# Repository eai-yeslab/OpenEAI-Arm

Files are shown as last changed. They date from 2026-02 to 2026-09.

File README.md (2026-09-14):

# OpenEAI-Arm

Open-source, low-cost, reproducible desktop robot hardware for embodied AI and real-world manipulation.

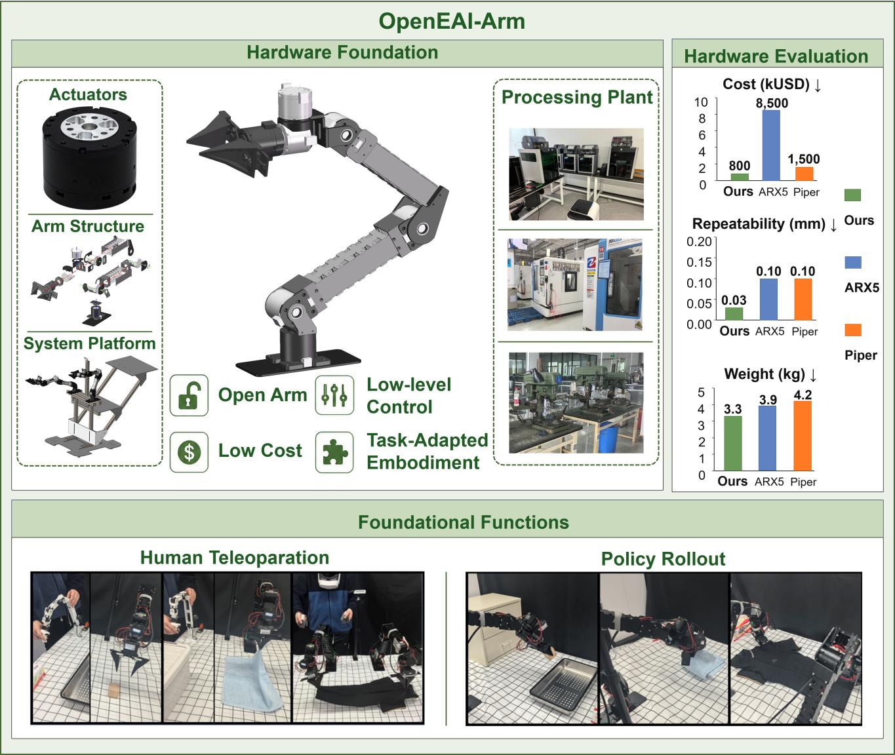
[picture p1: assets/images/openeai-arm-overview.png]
OpenEAI-Arm overview


OpenEAI-Arm is a 6-DoF serial robot arm with an independently controlled end-effector channel. It is designed for embodied-AI research, robot-control development, real-world policy evaluation, teleoperation, and Vision-Language-Action (VLA) data collection. The repository provides the mechanical design, manufacturing files, robot model, low-level control stack, ROS 2 integration, teleoperation examples, and data-collection tools needed to reproduce and extend the platform.

The design prioritizes a practical balance among workspace, payload, mass, manufacturability, control access, and cost. It can be used as a complete experimental platform or as an open hardware foundation for replacing actuators, modifying links, integrating new end effectors, and building synchronized dual-arm systems.

> [!WARNING]
> A robot arm can move unexpectedly and generate hazardous forces. Rigidly secure the base, keep the workspace clear, verify the emergency stop, and begin with simulation followed by unloaded, low-speed, small-angle tests. Never hot-plug the 24 V power or CAN wiring.

## OpenEAI Ecosystem

OpenEAI-Arm is the robot-hardware and control foundation of the OpenEAI platform:

- [OpenEAI-VLA](https://github.com/eai-yeslab/OpenEAI-VLA) provides the Vision-Language-Action research and deployment stack.
- [OpenEAI-FOC](https://github.com/ZJYSII/OpenEAI-FOC) develops open joint hardware, drive electronics, sensing, and field-oriented motor control.
- OpenEAI-Arm connects policies to a reproducible physical system through kinematics, dynamics-aware control, CAN communication, ROS 2, teleoperation, and safety limits.

```text
OpenEAI-VLA policy and data pipeline
                  │ actions
                  ▼
OpenEAI-Arm coordination, kinematics, teleoperation, and safety
                  │ joint targets
                  ▼
OpenEAI-FOC / compatible joint actuators and end effector
                  │
                  └──────── joint state and sensor feedback ────────┘
```

## Highlights

### Open hardware

- Six rotary joints plus one independently controlled end-effector channel
- Modular actuators, links, base, cable routing, and end-effector interface
- BOM, STEP, STL, mechanical drawings, URDF/SDF, and assembly documentation
- Replaceable gripper, dexterous-hand, or sensor interface
- Suitable for single-arm, dual-arm, and task-adapted embodiments

### Open control stack

- C++ core library, Python bindings, and ROS 2 nodes
- CAN-based joint and end-effector communication
- Joint-space, end-effector incremental, and end-effector absolute-pose control
- Gravity, inertia, Coriolis, and friction compensation in the low-level stack
- Jerk-limited S-curve interpolation for smoother target execution
- Simulation and visualization through the shared robot model

### Teleoperation and embodied-AI workflows

- GELLO master-slave joint control
- SpaceMouse incremental Cartesian control
- VR absolute-pose teleoperation over UDP
- Single-arm and dual-arm operation with isolated configurations and topics
- Synchronized image, joint-state, and action collection for VLA datasets
- Policy rollout examples for real-world manipulation

## System Specifications

The following values describe the documented OpenEAI-Arm V0.9 prototype. Payload, speed, accuracy, and thermal performance depend on assembly quality, calibration, controller settings, end-effector mass, and operating conditions.

| Parameter | Specification |
| --- | --- |
| Active degrees of freedom | 6 |
| End-effector control channels | 1 |
| Maximum reach | 636.7 mm |
| Arm mass | 3.3 kg, excluding gripper |
| Nominal end payload | 2 kg, excluding gripper |
| Nominal power | 420 W |
| Peak current | 17.5 A |
| Theoretical maximum end-effector speed | 1.6 m/s |
| Rated joint torque | J1-J3: 9 N·m; J4-J7: 3 N·m |
| Maximum static joint torque | J1-J3: 27 N·m; J4-J7: 7 N·m |
| Prototype repeatability | ±0.03 mm |
| Gripper force range | 0.5-5 N |
| Joint and end-effector bus | CAN |
| Power input | 24 V DC, XT30 2+2 |
| Documented manufacturing cost | Approximately CNY 5,500 |
| Recommended environment | 0-40 °C; non-waterproof |

The comparison charts in the overview image are project evaluation results. When reproducing them, report the hardware revision, payload, trajectory, warm-up state, measurement equipment, sample count, and calculation method.

## Kinematics

The controller uses Modified Denavit-Hartenberg parameters matching the CAD and URDF. The fixed mechanical angle is `β = 13.85°`.

| Joint | θ (deg) | a (mm) | d (mm) | α (deg) |
| --- | ---: | ---: | ---: | ---: |
| J1, base rotation | 0 | 0 | 106.26 | 0 |
| J2, shoulder pitch | 180 | 19 | 0 | -90 |
| J3, elbow flexion | 180 + β | 269 | 0 | 180 |
| J4, wrist deviation | -β | 236.12 | 0 | 0 |
| J5, wrist pitch | 90 | 80 | 0 | 90 |
| J6, tool rotation | 0 | 0 | 29 | 90 |

The end-effector mounting envelope is approximately 57 mm × 35 mm and uses four M3 fasteners. Communication and power can be routed through the final joint using the CAN and XT30 2+2 harness.

## Repository Layout

```text
OpenEAI-Arm/
├─ hardware/
│  ├─ bom/                    # Bill of materials
│  ├─ STEP/                   # Assemblies and manufacturable CAD
│  ├─ stl/                    # Printable and visualization meshes
│  ├─ drawings/               # DWG/PDF manufacturing drawings
│  └─ assembly/               # Assembly documentation
├─ software/
│  ├─ configs/                # Arm, CAN, motor, zero, and limit settings
│  ├─ include/ and src/       # C++ control library
│  ├─ python/                 # Python bindings
│  ├─ ros2/                   # ROS 2 nodes, robot model, and examples
│  ├─ scripts/                # Visualization and utility scripts
│  └─ tests/                  # Hardware and software test programs
├─ assets/                    # README images and videos
├─ LICENSE
└─ THIRD_PARTY_NOTICES
```

- Hardware index: [`hardware/README.md`](hardware/README.md)
- Software, control, and teleoperation guide: [`software/README.md`](software/README.md)
- Default real-arm configuration: [`software/configs/default.yml`](software/configs/default.yml)
- ROS 2 node: [`software/ros2/src/openeai_arm/src/OpenEAIArm_node.cpp`](software/ros2/src/openeai_arm/src/OpenEAIArm_node.cpp)
- Control and data-collection examples: [`software/ros2/src/openeai_arm/examples/`](software/ros2/src/openeai_arm/examples/)

## Quick Start

### 1. Prepare the system

Ubuntu 22.04 and ROS 2 Humble are recommended.

```bash
sudo apt update
sudo apt install git build-essential cmake libyaml-cpp-dev libeigen3-dev liburdf-dev

git clone https://github.com/eai-yeslab/OpenEAI-Arm.git
cd OpenEAI-Arm/software
```

A Python 3.10 environment is recommended for keeping robot dependencies isolated:

```bash
conda create -n openeai python=3.10
conda activate openeai
```

Pinocchio, KDL, the Dynamixel SDK, and optional teleoperation dependencies require additional setup. Follow [`software/README.md`](software/README.md) before building the complete stack.

### 2. Build

Build the C++ library, ROS 2 packages, and Python bindings from the `software/` directory:

```bash
cmake -S . -B build -DCMAKE_BUILD_TYPE=Release
cmake --build build --target extra -j 8
```

To build the components separately:

```bash
# C++ core and tests
cmake -S . -B build -DCMAKE_BUILD_TYPE=Release
cmake --build build -j 8

# Python package
cmake -S . -B build -DCMAKE_BUILD_TYPE=Release \
  -DPYTHON_EXECUTABLE=$(python3 -c "import sys; print(sys.executable)")
cmake --build build --target pip_install -j 8

# ROS 2 workspace
cmake --build build --target ros2
source ros2/install/setup.bash
```

### 3. Verify in simulation first

Terminal 1:

```bash
cd OpenEAI-Arm/software
source ros2/install/setup.bash
ros2 launch openeai_arm_urdf_ros2 launch.py
```

Terminal 2:

```bash
cd OpenEAI-Arm/software
source ros2/install/setup.bash
ros2 run openeai_arm OpenEAIArm_node --ros-args \
  -p ctrl_mode:=2 -p frequency:=50
```

Use simulation to verify the robot model, coordinate frames, joint directions, reachable workspace, and topics. Stop the node before changing between simulation and real-hardware modes.

### 4. Configure the real arm

Before applying power, inspect [`software/configs/default.yml`](software/configs/default.yml):

- Serial device and communication settings
- CAN master/slave IDs for all six joints and the gripper
- Joint zero positions and direction signs
- Position, velocity, acceleration, and torque limits
- URDF path and end-effector configuration

The public default configuration uses `/dev/ttyACM0`, but the actual device path may differ. The first two actuator IDs in the public configuration are intentionally ordered differently from a simple `1, 2, ...` sequence; verify every physical joint against the configuration instead of assuming numeric order.

Add the user to the serial-device group if required, then log out and back in:

```bash
sudo usermod -aG dialout $USER
```

### 5. Start the real arm

Rigidly mount the base, clear the workspace, support the arm against an uncontrolled drop, and make the emergency stop immediately reachable.

```bash
cd OpenEAI-Arm/software
source ros2/install/setup.bash
ros2 run openeai_arm OpenEAIArm_node --ros-args \
  -p ctrl_mode:=0 -p frequency:=50 \
  -p config:=configs/default.yml
```

Inspect the current state before sending any target:

```bash
ros2 topic echo /openeai_arm/joint_states --once
ros2 topic echo /openeai_arm/eef_pose --once
ros2 topic hz /openeai_arm/joint_states
```

The `position` target contains seven values:

```text
[J1, J2, J3, J4, J5, J6, gripper]
```

Read the current position first. For initial motion, copy the current seven-value target and change only one joint by approximately 0.03-0.05 rad. Do not copy joint values from another arm.

## Control Modes

| Function | Settings | Purpose |
| --- | --- | --- |
| Joint position control | `ctrl_mode:=0`, `ee_pose:=0` | Send six joint targets plus gripper |
| Drag teaching | `ctrl_mode:=1` | Manually guide the arm while publishing joint state |
| Simulation | `ctrl_mode:=2` | Validate the model and control interface without motors |
| End-effector increments | `ctrl_mode:=0`, `ee_pose:=1` | Incremental Cartesian commands, typically SpaceMouse |
| Absolute end-effector pose | `ctrl_mode:=0`, `ee_pose:=2` | Absolute pose input, typically VR |

### GELLO master-slave control

```bash
ros2 run openeai_arm OpenEAIArm_node --ros-args \
  -p ctrl_mode:=0 -p frequency:=50 -p arm_name:=left

cd ros2/src/openeai_arm/examples
python gello_controller.py
```

### SpaceMouse control

```bash
sudo apt install libhidapi-dev
pip install git+https://github.com/bglopez/python-easyhid.git
pip install pyspacemouse

ros2 run openeai_arm OpenEAIArm_node --ros-args \
  -p ctrl_mode:=0 -p ee_pose:=1 -p frequency:=50

cd ros2/src/openeai_arm/examples
python spacemouse.py
```

### VR control

The example expects UDP data in the form `[x, y, z, qx, qy, qz, qw, gripper]` at approximately 50 Hz.

```bash
ros2 run openeai_arm OpenEAIArm_node --ros-args \
  -p ctrl_mode:=0 -p ee_pose:=2 -p frequency:=50

cd ros2/src/openeai_arm/examples
python vr.py
```

Validate direction, scale, coordinate frames, and initial-pose alignment in simulation before connecting the real arm.

## Dual-Arm Operation

Use independent device paths, node names, configurations, and target topics. Calibrate and test each arm separately before running both together.

```bash
# Left arm
ros2 run openeai_arm OpenEAIArm_node --ros-args \
  -p ctrl_mode:=0 -p frequency:=50 -p arm_name:=left \
  -r /joint_targets:=/left/joint_targets

# Right arm
ros2 run openeai_arm OpenEAIArm_node --ros-args \
  -p config:=configs/default_right.yml \
  -p ctrl_mode:=0 -p frequency:=50 -p arm_name:=right \
  -r /joint_targets:=/right/joint_targets
```

## VLA Data Collection

The examples support synchronized camera images, joint states, and actions. Start the arm, launch the required USB or RealSense camera nodes, and then run:

```bash
cd ros2/src/openeai_arm/examples
python collect_data.py --task_name pick_place --config config_left.yml
```

For dual-arm capture, see `config_multi.yml`. Record a short sample first and verify timestamps, dimensions, camera views, joint order, action units, and gripper values before collecting a full dataset.

## Recommended Test Sequence

1. Inspect the base, fasteners, cable routing, end effector, work area, and emergency stop.
2. Confirm the device path, CAN IDs, zero positions, direction signs, and limits.
3. Start RViz or drag mode and verify the pose and coordinate conventions.
4. Start the real node and confirm that all seven channels report continuous state.
5. Perform an unloaded, small-angle, single-joint motion test.
6. Run the target function while monitoring communication, current, temperature, and mechanical behavior.
7. Stop teleoperation or policy commands, return to a supported safe pose, and stop the arm node.
8. Confirm that the motors are disabled, support the arm, and disconnect 24 V power before adjustment or disassembly.

Immediately stop and disconnect power after unintended motion, collision, unusual noise, persistent CAN loss, overcurrent, overheating, burning odor, structural looseness, or high-frequency oscillation.

## Frequently Asked Questions

### The serial device cannot be opened

Check the actual `/dev/ttyACM*` or `/dev/ttyUSB*` path, USB cable, group permissions, and `can_config.id`. Reconnect only while power is safely removed, and log in again after changing `dialout` membership.

### A CAN node is missing or repeatedly disconnects

Power down first. Verify the 24 V supply, CAN high/low wiring, termination, bus rate, physical node IDs, and the master/slave IDs in the selected YAML configuration.

### A joint moves in the wrong direction

Use the emergency stop, correct the direction or zero setting in the configuration, and repeat an unloaded low-speed test. Do not compensate for a reversed joint only at the high-level policy layer.

### The arm jitters after startup

Stop motion and check the zero position, direction, encoder installation, structural fasteners, update frequency, and controller gains. Reduce gains and target changes before retesting.

### End-effector control jumps

Check units, reference pose, quaternion convention, coordinate frames, inverse-kinematics result, and initial alignment. Reproduce the command in simulation and reduce the increment or pose change.

### Pinocchio cannot be found

Check the installed Python version and the `PATH`, `PKG_CONFIG_PATH`, `LD_LIBRARY_PATH`, `PYTHONPATH`, and `CMAKE_PREFIX_PATH` entries for `/opt/openrobots`.

### Dual-arm topics interfere with each other

Use separate device paths, configuration files, arm names, node names, namespaces, and remapped target topics. Test each arm independently before enabling simultaneous motion.

## Citation

If OpenEAI-Arm contributes to your research, please cite the OpenEAI-Platform paper and identify the repository version or commit used:

```bibtex
@inproceedings{openeai_platform,
  title  = {OpenEAI-Platform: Open-source Embodied Artificial Intelligence Hardware-Software Unified Platform},
  author = {Jinyuan Zhang and Luoyi Fan and Leiyu Wang and Yeqiang Wang and Yichen Zhu and Cewu Lu and Nanyang Ye},
  year   = {2026}
}
```

## License

OpenEAI-Arm is licensed under the [BSD 3-Clause License](LICENSE). Third-party components remain subject to their respective licenses; see [`THIRD_PARTY_NOTICES`](THIRD_PARTY_NOTICES).

## Contributing and Support

Issues and pull requests are welcome. Include the hardware revision, operating system, configuration, supply conditions, command sequence, logs, and reproducible steps. For safety-related reports, describe the physical setup and tested limits.

- Repository: <https://github.com/eai-yeslab/OpenEAI-Arm>
- Open an issue for questions, bugs, or proposed changes
- Contact: ynylincoln@sjtu.edu.cn

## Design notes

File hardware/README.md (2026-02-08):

# Hardware

This directory contains all hardware-related files for the OpenEAI Arm.

## Directory Structure

- **STEP/** - files in STEP format
- **stl/** - 3D printable STL files
- **drawings/** - CAD drawings in PDF format
- **bom/** - Bill of Materials (XLSX format)
- **assembly/** - Assembly instructions in PDF format

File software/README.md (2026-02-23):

# OpenEAI-ARM

This is the open-source control software for the OpenEAI-ARM robot.

## Prerequisites

First, make sure you have some basic building tools on your machine. You can install them by:

```bash
sudo apt install git build-essential cmake
```

Then, clone the repository:

```bash
git clone https://github.com/eai-yeslab/OpenEAI-Arm.git
```

Since some of the third-party dependencies will use python bindings, we also recommend setting up a python virtual environment to avoid conflicts with your system python packages. You can set up a virtual environment with the following commands:

```bash
conda create -n openeai python=3.10
conda activate openeai
```

## Third-party Dependencies

This project relys on the following third-party packages:
- yaml-cpp for reading config files
- Eigen3 library for matrix calculations
- URDF library for urdf reading
- [pinocchio](https://gepettoweb.laas.fr/doc/stack-of-tasks/pinocchio/master/doxygen-html/md_doc_b_examples_a_model.html) for inverse kinetics
- [KDL](https://www.orocos.org/wiki/orocos/kdl-wiki.html)
- [kdl_parser](https://github.com/ros/kdl_parser?tab=readme-ov-file) and [urdf](https://github.com/ros/urdf) packages, whose source codes are already included so that they can be used without installing ros
- [Dynamixel SDK](https://github.com/ROBOTIS-GIT/DynamixelSDK/tree/main) for controlling [GELLO](https://wuphilipp.github.io/gello_site/)

### yaml-cpp, Eigen3, URDF Installation

Run `sudo apt install libyaml-cpp-dev libeigen3-dev liburdf-dev` to install yaml-cpp, Eigen3, and URDF library.

### Dynamixel SDK Installation

Simply `cd` to its python directory and install:

```bash
cd third_party/DynamixelSDK/python
pip install -e .
```

### Pinocchio Installation

In this project we use pinocchio to calculate inverse kinetics. To install this library run the following commands as described in the [official installation website](https://stack-of-tasks.github.io/pinocchio/download.html#Install_3). Note this may take a while:

```bash
sudo apt install -qqy lsb-release curl

sudo mkdir -p /etc/apt/keyrings
curl http://robotpkg.openrobots.org/packages/debian/robotpkg.asc \
    | sudo tee /etc/apt/keyrings/robotpkg.asc

echo "deb [arch=amd64 signed-by=/etc/apt/keyrings/robotpkg.asc] http://robotpkg.openrobots.org/packages/debian/pub $(lsb_release -cs) robotpkg" \
| sudo tee /etc/apt/sources.list.d/robotpkg.list

sudo apt update

sudo apt install -qqy robotpkg-py3*-pinocchio
```

And then modify the following environment variables or add to `$HOME/.bashrc` for persistent configuration:

```bash
export PATH=/opt/openrobots/bin:$PATH
export PKG_CONFIG_PATH=/opt/openrobots/lib/pkgconfig:$PKG_CONFIG_PATH
export LD_LIBRARY_PATH=/opt/openrobots/lib:$LD_LIBRARY_PATH
export PYTHONPATH=/opt/openrobots/lib/python3.10/site-packages:$PYTHONPATH # Adapt your desired python version here
export CMAKE_PREFIX_PATH=/opt/openrobots:$CMAKE_PREFIX_PATH
```

### KDL Installation

[KDL](https://github.com/orocos/orocos_kinematics_dynamics/tree/master) (Kinetics and Dynamics Library) requires Eigen3 library to install. To install, run the following commands:

```bash
git clone https://github.com/orocos/orocos_kinematics_dynamics.git
cd orocos_kinematics_dynamics/orocos_kdl
mkdir build
cd build
cmake .. -DCMAKE_BUILD_TYPE=Release
make
sudo make install
```

## Build and Installation

In this project, we use cmake to build the control program.

### All

We provide an option to build everything, including basic C++ library, ROS2 pacakge, and python package installation via pip. This can be completed via:

```bash
cmake -S . -B build -DCMAKE_BUILD_TYPE=RELEASE
cmake --build build --target extra
```

If you don't want to build all of them, you can build them one by one following the instructions below.

### C++

C++ libraries are core libraries to control OpenEAI-Arm. The commands are:

```bash
cmake -S . -B build -DCMAKE_BUILD_TYPE=RELEASE
cmake --build build -j 8
```

An example of the usage can be found at [tests/test_openeai_arm.cpp](tests/test_openeai_arm.cpp), whose brinary is located at [build/test_openeai_arm](build/test_openeai_arm). If you want to run it, make sure your robotic arm is well-assembled, as the program will move the robotic arm.

### Python

To build python packages and install via pip, run:
```bash
cmake -S . -B build -DCMAKE_BUILD_TYPE=RELEASE -DPYTHON_EXECUTABLE=$(python3 -c "import sys; print(sys.executable)")
cmake --build build --target pip_install -j 8 
```

### ROS2

ROS2 packages can be built with cmake:

```bash
cmake --build build --target ros2 
```

Or, after run the commands for building C++ libraries, run:

```bash
cd ros2
colcon build --symlink-install
```

After building the package, add it to the environment:

```bash
cd ros2/install # or cd install
source setup.bash
```

And start the arm node:

```bash
cd ../..
ros2 run openeai_arm OpenEAIArm_node --ros-args -p ctrl_mode:=0 -p frequency:=50 # 0 for program control mode, 1 for drag mode, 2 for sim mode
```

You can also set `-p ee_pose:=1` for delta ee pose control, and `-p ee_pose:=2` for absolute ee pose control.

If you want to run two arms at the same time, you can use:

```bash
ros2 run openeai_arm OpenEAIArm_node --ros-args -p ctrl_mode:=0 -p frequency:=50 -p arm_name:=left -r /joint_targets:=/left/joint_targets
ros2 run openeai_arm OpenEAIArm_node --ros-args -p config:=configs/default_right.yml -p ctrl_mode:=0 -p frequency:=50 -p arm_name:=right -r /joint_targets:=/right/joint_targets
```

where [configs/default_right.yml](configs/default_right.yml) is the config file for another arm.

An example of python ROS2 controller can be found at [ros2/src/openeai_arm/examples/OpenEAIArmROS2Operator.py](ros2/src/openeai_arm/examples/OpenEAIArmROS2Operator.py), which provides `get_frame()` function to collect the latest data from robotic arm, cameras, etc. with synchronized timestamps.

To switch the control mode when the node is running, you can publish to the topic `/set_control_mode` with message type `sensor_msgs/msg/JointState`, where the first data is the control mode you want to switch to, 0 for program control mode and 1 for drag mode, where the sim mode does not support switching to and from; and the second data is the ee pose mode, 0 for joint control, 1 for delta ee pose control, and 2 for absolute ee pose control. For example, to switch to drag mode under joint control, you can run:

```bash
ros2 topic pub /set_control_mode sensor_msgs/msg/JointState "header:
  stamp:
    sec: 0
    nanosec: 0
  frame_id: ''
name: []
position: [1.0, 0.0]
velocity: []
effort: []" -1
```

or you can write your own script to publish the message.

## Control

### Basic Settings

To run this control library with your own robotic arm, first assign a unique master id and slave id to each motor, as described in [Damiao's official tutorial](https://gl1po2nscb.feishu.cn/wiki/LjOXwEqNCiqThpk1IIycHoranlb). Next, align the robotic arm to be parallel with the table, and record the positions of the motors. You can either set this position to be the motors' zero points, or record them in the config file.

Then, based on your settings, modify the parameters in the config file. The default config file is stored at `configs/default.yml`, but it is recommanded to create a copy before modifying any options. Some important parameters include:

- `can_config.id` and `can_config.baud_rate`, which is the port path of Damiao's USB2CAN device. 
- `urdf.path` pointing to the urdf path if it is changed
- For each motor, modify `type`, `reset_pose`, `master_id` and `slave_id` if necessary. The motors are from bottem (base) to top (end effector). **Please note in the default setting, the first motor has slave_id to be 0x02, and the second has 0x01, !!modify this based on your own settings!!** 

## Data collection

OpenEAI-arm supports human manipulation for further training. We provide an example data collection code based on ROS2 in [ros2/src/openeai_arm/examples/collect_data.py](ros2/src/openeai_arm/examples/collect_data.py) using , and you can write your own data collection scripts with/without ROS2. 

To run the data collection code in ROS2, first compile the ros2 package as described before. Then, start the arm node and camera node:

```bash
# Start Arm node
ros2 run openeai_arm OpenEAIArm_node --ros-args -p ctrl_mode:=0 -p frequency:=50 -p arm_name:=left -r /joint_targets:=/left/joint_targets

# You should adapt these camera nodes to your own camera settings, here are just some examples

# Start USB Camera node (not recommended, use realsense if possible)
ros2 run usb_cam usb_cam_node_exe --ros-args -p video_device:=/dev/video0 -p image_width:=640 -p image_height:=480 -p framerate:=30.0

# Start Realsense Camera node
ros2 launch realsense2_camera rs_launch.py camera_namespace:=camera camera_name:=agentview depth_module.depth_profile:=640x480x30 rgb_camera.color_profile:=640x480x30 enable_rgbd:=true enable_sync:=true align_depth.enable:=true enable_color:=true enable_depth:=true serial_no:="'335222074022'" # D435i
ros2 launch realsense2_camera rs_launch.py camera_namespace:=camera camera_name:=eyeview depth_module.depth_profile:=640x480x30 depth_module.color_profile:=640x480x30 depth_module.infra_profile:=640x480x30 enable_rgbd:=true enable_sync:=true align_depth.enable:=true enable_color:=true enable_depth:=true serial_no:="'218722270624'" # D405

# Start GELLO controller and Data Collection scripts
cd ros2/src/openeai_arm/examples
python collect_data.py --task_name pick_place --config config_left.yml
```

You can modify the parameters in [ros2/src/openeai_arm/examples/config_left.yml](ros2/src/openeai_arm/examples/config_left.yml) based on your environment in ROS2.

If you want to collect data for two (multiple) arms, refer to [ros2/src/openeai_arm/examples/config_multi.yml](ros2/src/openeai_arm/examples/config_multi.yml) for example config file.

### Control With GELLO

[GELLO manipulation](https://wuphilipp.github.io/gello_site/) is a simple and effective way to control robotic arms. We provide an example code to use GELLO as controller in ROS2. To use it, 
first start the ROS2 arm node in normal mode:

```bash
ros2 run openeai_arm OpenEAIArm_node --ros-args -p ctrl_mode:=0 -p frequency:=50 -p arm_name:=left
```

Then run the following scripts:

```bash
cd ros2/src/openeai_arm/examples
python gello_controller.py
```

This script will connect to GELLO device and broadcast the joint targets to the arm node at topic `/joint_targets`.

### Control With SpaceMouse

We also provide an example code to use spacemouse as controller. To install the dependencies for [pyspacemouse](https://spacemouse.kubaandrysek.cz/#linux), run:

```bash
sudo apt-get install libhidapi-dev
pip install git+https://github.com/bglopez/python-easyhid.git
echo 'KERNEL=="hidraw*", SUBSYSTEM=="hidraw", MODE="0664", GROUP="plugdev"' | sudo tee /etc/udev/rules.d/99-hidraw-permissions.rules
sudo usermod -aG plugdev $USER
newgrp plugdev

pip install pyspacemouse
```

And run scripts in ROS2:

```bash
cd ros2/src/openeai_arm/examples
python spacemouse.py
```

Then, start the ros2 node in delta ee pose mode (set `ee_pose:=1`):

```bash
ros2 run openeai_arm OpenEAIArm_node --ros-args -p ctrl_mode:=0 -p frequency:=50 -p arm_name:=left -r /joint_targets:=/left/joint_targets -p ee_pose:=1
```

### Control With VR

We also provide an example to manipulate the arm with VR devices. To use it you need to have a server program running on your VR device and receive UDP packages in the format described in [ros2/src/openeai_arm/examples/vr.py](ros2/src/openeai_arm/examples/vr.py#48). First, start the ROS2 node for arm in absolute ee pose mode (`ee_pose:=2`):

```bash
ros2 run openeai_arm OpenEAIArm_node --ros-args -p ctrl_mode:=0 -p frequency:=50 -p arm_name:=left -r /joint_targets:=/left/joint_targets -p ee_pose:=2

ros2 run openeai_arm OpenEAIArm_node --ros-args -p config:=configs/default_right.yml -p ctrl_mode:=0 -p frequency:=50 -p arm_name:=right -r /joint_targets:=/right/joint_targets -p ee_pose:=2
```

Then, run `vr.py` to receive and retrieve handle poses to robotic poses:

```bash
python vr.py
```

Hold B to command the arm to prepare position, and release B to start manipulation **after the robotic arm reaches the prepare position and your VR controller is in the correct pose**. Press `A` to stop sending position to the arm until holding and releasing `B` again. Hold `Y` to retract the arm.

**Note:** We recommand you to first using simulation mode to test the VR controlling before manipulating the real arm. set `ctrl_mode:=2` to use simulation mode.

## Simulation

We provide a launch file to launch simulation in ROS2 via rviz2. To start the simulation interface, run:

```bash
ros2 launch openeai_arm_urdf_ros2 launch.py
```

and run ROS2 arm node in sim mode by setting `ctrl_mode` to be 2:

```bash
ros2 run openeai_arm OpenEAIArm_node --ros-args -p ctrl_mode:=2 -p frequency:=50
```

## Inference

To run inference with a trained model, you can use the provided FastAPI server. First, ensure you have a trained model checkpoint, then, modify `CKPT_PATH` in [OpenEAI-VLA/openeai/infer.py](OpenEAI-VLA/openeai/infer.py) to point to your checkpoint path.

Then, start the inference server by running:

```bash
cd ros2/src/openeai_arm/examples
python inference.py --task_instruction "do something" --contiguous --config_path config_left_inference.yml --server_host 127.0.0.1 --server_port 8000
```

You can modify [OpenEAI-Arm/ros2/src/openeai_arm/examples/config_left_inference.yml](OpenEAI-Arm/ros2/src/openeai_arm/examples/config_left_inference.yml) based on your own settings.

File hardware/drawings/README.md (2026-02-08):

# Technical Drawings

This directory contains technical drawings in PDF and DWG format for the OpenEAI Arm.

These drawings provide detailed dimensions and specifications for manufacturing and assembly.

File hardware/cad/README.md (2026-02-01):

# CAD Files

This directory contains CAD files in STEP format for the OpenEAI Arm.

STEP files are industry-standard 3D CAD files that can be opened in most CAD software packages.

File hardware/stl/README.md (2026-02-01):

# STL Files

This directory contains STL files for 3D printing parts of the OpenEAI Arm.

STL files can be used directly with slicing software for 3D printing.

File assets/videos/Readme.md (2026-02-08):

# Videos

This directory contains video content related to the OpenEAI Arm project.

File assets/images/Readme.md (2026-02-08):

# Images

This directory contains images and photos related to the OpenEAI Arm project.

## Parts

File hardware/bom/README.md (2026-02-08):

# Bill of Materials (BOM)

This directory contains the Bill of Materials for the OpenEAI Arm in XLSX format.

The BOM lists all components, quantities, and sourcing information needed to build the arm.

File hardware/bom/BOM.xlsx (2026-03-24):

Material | Subassembly Belongings | Character | Quantity | Price(RMB) | Price(USD) | Purchase
JXS-01-01 | STEP1 | 6061 Aluminum | 1 | <1400 | <200 | Manufacturing
JXS-01-02 | STEP1 |  | 1
JXS-01-03 | STEP1 |  | 1
JXS-01-04 | STEP1 |  | 1
JXS-01-05 | STEP1 |  | 1
JXS-02-01 | STEP2\3 |  | 4
JXS-02-02 | STEP2\3 |  | 4
JXS-02-03 | STEP2 |  | 2
JXS-02-04 | STEP2 |  | 2
JXS-03-01 | STEP3 |  | 1
JXS-03-02 | STEP3 |  | 1
JXS-04-01 | STEP4 |  | 1
JXS-04-02 | STEP4 |  | 1
JXS-04-03 | STEP4 |  | 1
JXS-04-04 | STEP4 |  | 1
JXS-04-05 | STEP4 |  | 1
JXS-04-06 | STEP4 |  | 1
JXS-04-07 | STEP4 |  | 1
JXS-05-01 | STEP5 |  | 1
B6704ZZ | STEP2\3\4 | Bearing Steel | 3 | 10.38 | 1.5 | https://e.tb.cn/h.ia5PtiowQPkVhvE?tk=2lIBUKFAZoj
JXS-07-05 | GRIP | SLA | 1 |  |  | 3D printing
JXS-07-08 | GRIP | SLA | 1 |  |  | 3D printing
JXS-07-09 | GRIP | SLA | 1 |  |  | 3D printing
Clamping Jaw v3 | GRIP | SLA | 1 |  |  | 3D printing
Clamping Jaw v3 left | GRIP | SLA | 1 |  |  | 3D printing
Slider and Rail | GRIP |  | 2 | 76 | 11 | https://e.tb.cn/h.7AGLF0jUZUDXJjp?tk=wZmaUKFiw6g
switch | GRIP | 6061 Aluminum | 1 |  |  | 3D printing
casing2 | STEP2 | SLA | 1 |  |  | 3D printing
casing3 | STEP3 | SLA | 1 |  |  | 3D printing
DAMIAOJ4340 | ALL | motor | 3 | 2544 | 370 | DAMIAO
DAMIAOJ4310-2EC | ALL | motor | 3+1 | 2396 | 348 | DAMIAO
Power source 24V XT30 12A |  | Power Source | 1 | 90 | 13 | https://item.jd.com/10084543367630.html
Parallel Connection XT30 |  | Parallel Connection | 2 | 58 | 8.4 | https://e.tb.cn/h.7A4o7VFhj66tiTt?tk=ocFrUKFQPPY (https://item.taobao.com/item.htm?id=996289044875&skuId=5973666792008)
XT30 2+2 Wire 20cm | ALL |  | 3 | 31.5 | 4.56 | https://e.tb.cn/h.iZhQ6utcLtsRVfZ?tk=sKYsUKE1MLk
XT30 2+2 Wire 20cm straight + bent | ALL |  | 2 | 30 | 4.34
XT30 2+2 Wire 30cm | ALL |  | 3 | 42 | 6.08
Ball head pull rod M3 40mm | GRIP | Steel | 2 | 3.33 | 0.48 | https://e.tb.cn/h.7A4Q9qckt7PgGVO?tk=txeAUKF5MX4
M2screw | ALL | 304 Steel | 200 | ≈6 | ≈1 | https://e.tb.cn/h.ia5ccovAxU8BVyT?tk=qlBiUKFNj23
M3screw | ALL | 304 Steel | 200 | ≈6.5 | ≈1
M5screw | STEP1 | 304 Steel | 200 | ≈7 | ≈1
M3screw2 | ALL | 304 Steel | 100 | ≈3 | ≈0.5 | https://e.tb.cn/h.7AuZkvmwAsdF7XE?tk=TiSiUKFtPge
M3弹垫 | ALL | 304 Steel | 500 | 2.33 | 0.33 | https://e.tb.cn/h.ia57VBTVB2qIsj3?tk=0bYBUKFFsLV
M3螺母 | ALL | 304 Steel | 50 | 1.94 |  | https://e.tb.cn/h.ia58a2TkJB2xWVG?tk=60x6UKFwrnU
Tie 3*200 |  | Nylon | 100 | 7.75 | 2.43 | https://e.tb.cn/h.7Au3DzMf98FGadV?tk=uw8gUKFB4Qe

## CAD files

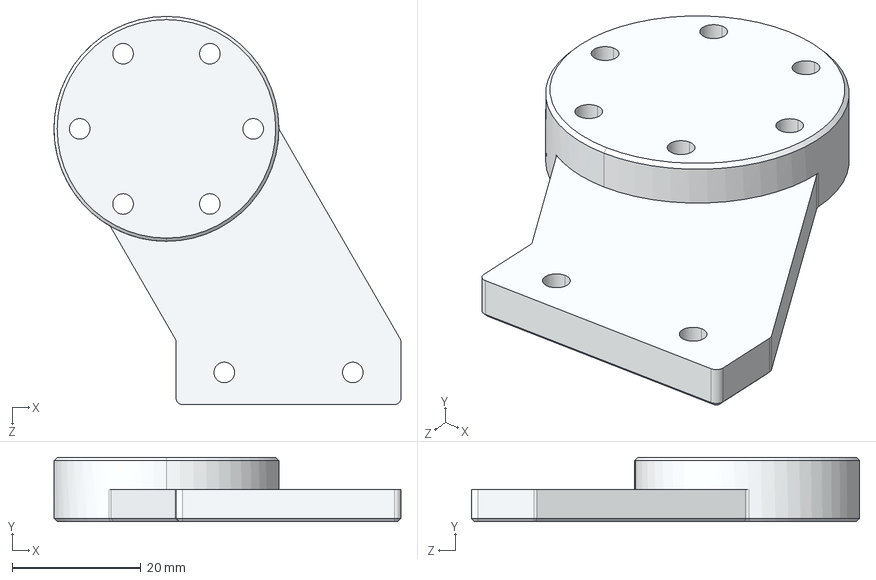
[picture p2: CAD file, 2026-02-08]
hardware/STEP/STEP1/JXS-01-05.STEP
54.0 x 10.0 x 60.4 mm

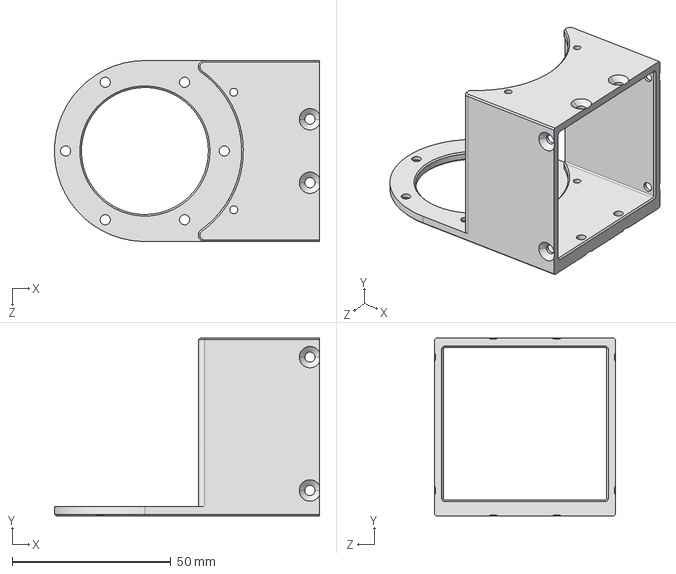
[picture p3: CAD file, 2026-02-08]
hardware/STEP/STEP2/JXS-02-03.STEP
83.5 x 56.0 x 57.0 mm

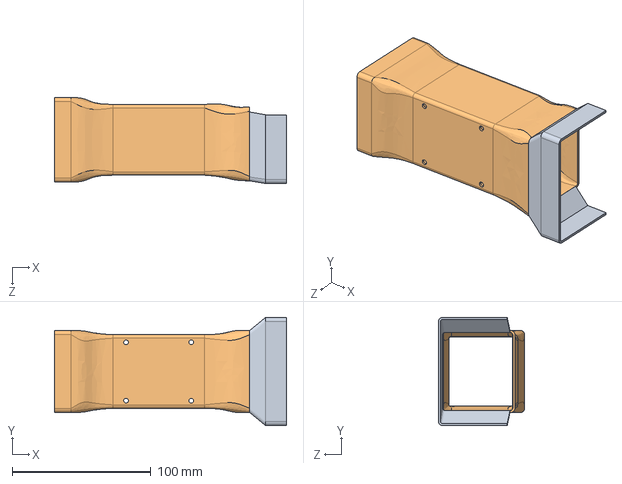
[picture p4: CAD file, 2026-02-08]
hardware/STEP/STEP3/casing3.STEP
167.0 x 78.0 x 62.0 mm

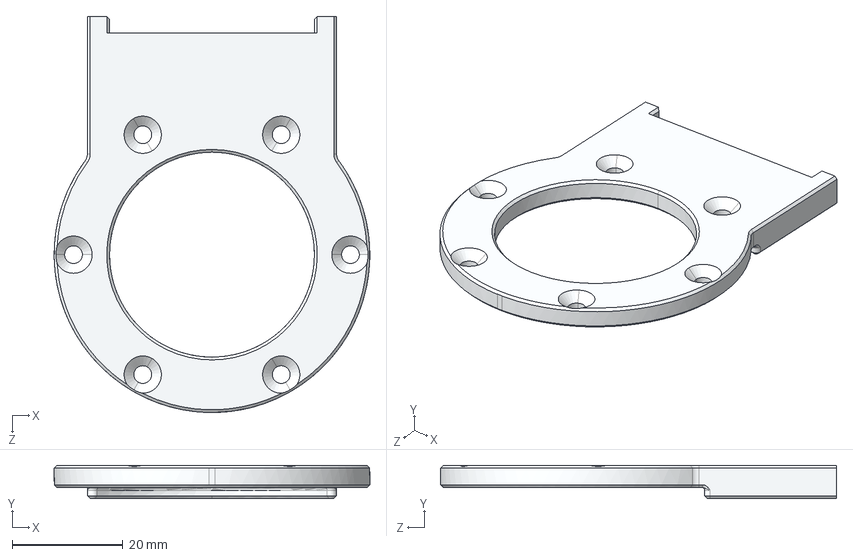
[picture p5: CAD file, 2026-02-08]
hardware/STEP/STEP4/JXS-04-05.STEP
57.0 x 6.00 x 71.5 mm

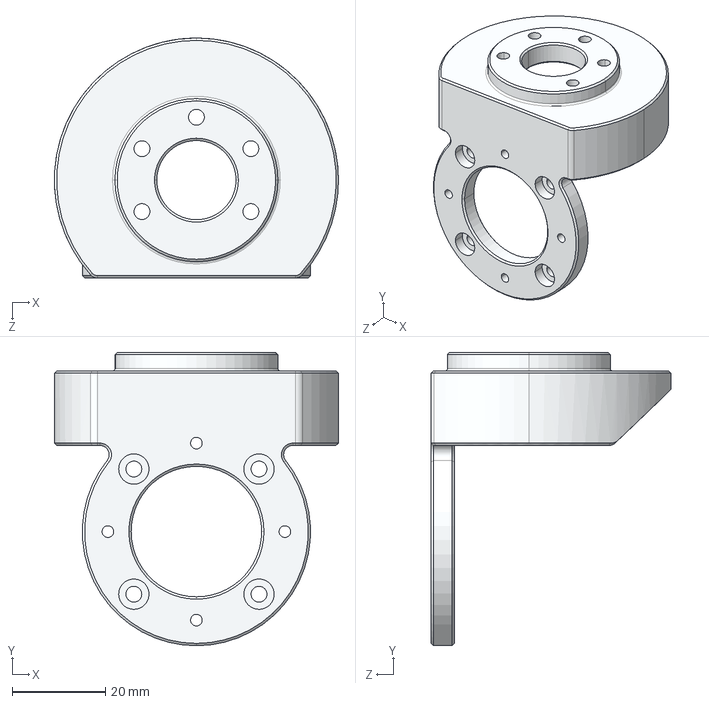
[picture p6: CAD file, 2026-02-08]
hardware/STEP/STEP5/JXS-05-01.STEP
61.0 x 63.0 x 51.5 mm

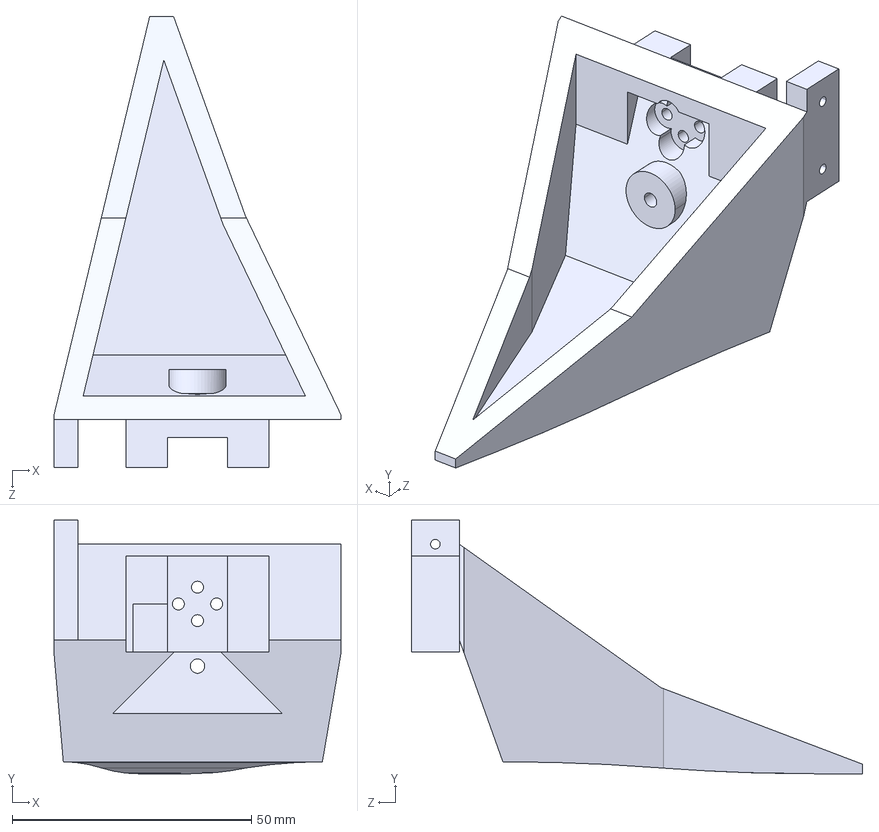
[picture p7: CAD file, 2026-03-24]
hardware/STEP/STEP6/Clamping Jaw v3.STEP
60.0 x 53.0 x 94.3 mm

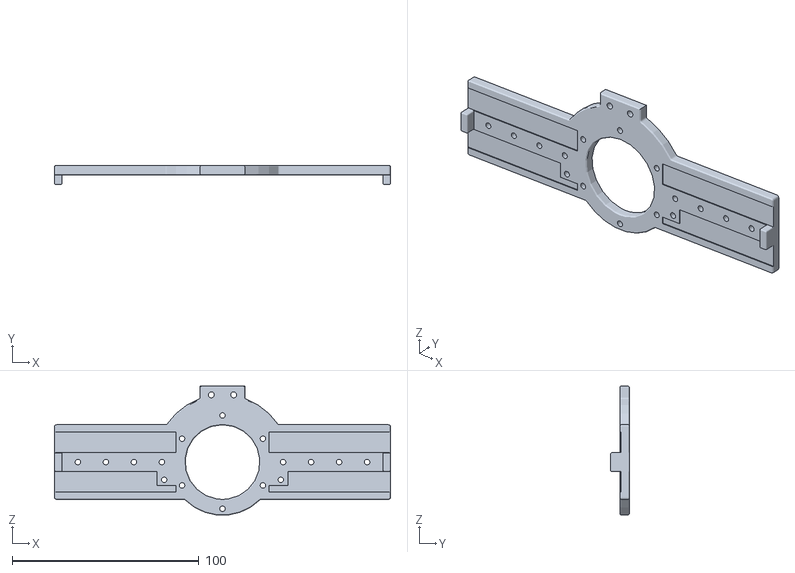
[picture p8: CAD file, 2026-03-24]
hardware/stl/GRIP/JXS-07-05.STL
180.0 x 10.0 x 69.0

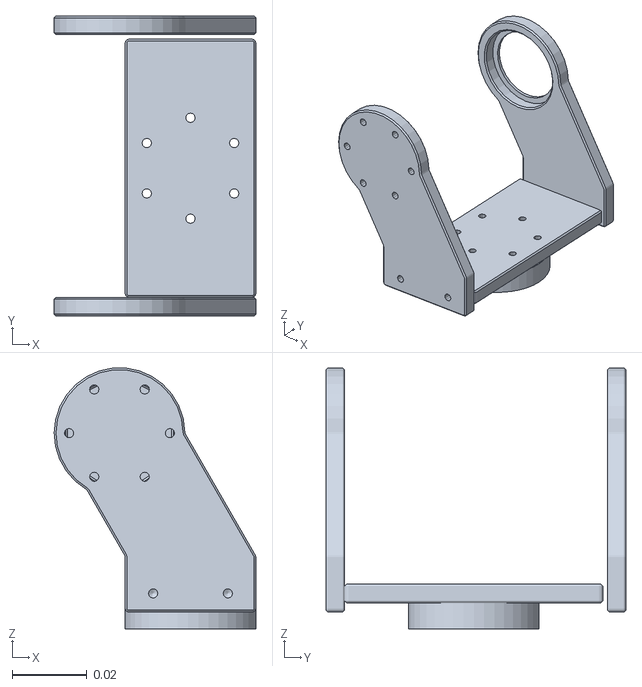
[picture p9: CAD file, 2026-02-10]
software/ros2/src/openeai_arm_urdf_ros2/meshes/link1.STL
0.054 x 0.0803 x 0.0698

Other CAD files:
hardware/drawings/STEP1/JXS-01-03.DWG
hardware/drawings/STEP2/JXS-02-03.DWG
hardware/drawings/STEP3/JXS-03-01.DWG
hardware/drawings/STEP4/JXS-04-01.DWG
hardware/drawings/STEP5/JXS-05-01.DWG
hardware/stl/casing3.STL
hardware/drawings/STEP1/JXS-01-02.DWG
hardware/drawings/STEP2/JXS-02-04.DWG
hardware/drawings/STEP3/JXS-03-02.DWG
hardware/drawings/STEP4/JXS-04-06.DWG
hardware/STEP/STEP1/JXS-01-01.STEP
hardware/STEP/STEP1/JXS-01-02.STEP
hardware/STEP/STEP1/JXS-01-03.STEP
hardware/STEP/STEP1/JXS-01-04.STEP
hardware/STEP/STEP2/B6704ZZ.STEP-1.SLDPRT
hardware/STEP/STEP2/JXS-02-01.STEP
hardware/STEP/STEP2/JXS-02-02.STEP
hardware/STEP/STEP2/JXS-02-04.STEP
hardware/STEP/STEP2/casing2.STEP
hardware/STEP/STEP3/JXS-03-01.STEP
hardware/STEP/STEP3/JXS-03-02.STEP
hardware/STEP/STEP4/JXS-04-01.STEP
hardware/STEP/STEP4/JXS-04-02.STEP
hardware/STEP/STEP4/JXS-04-03.STEP
hardware/STEP/STEP4/JXS-04-04.STEP
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

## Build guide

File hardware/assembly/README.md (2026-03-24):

# Assembly Instructions
TODO：
This directory contains assembly instructions in PDF format for the OpenEAI Arm.

Assembly guidelines will be released soon.

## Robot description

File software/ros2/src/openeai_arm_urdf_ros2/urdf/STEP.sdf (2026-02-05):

<sdf version='1.7'>
  <model name='STEP'>
    <link name='base_link'>
      <inertial>
        <pose>-2.3e-05 0 0.01623 0 -0 0</pose>
        <mass>0.50446</mass>
        <inertia>
          <ixx>0.00018822</ixx>
          <ixy>1.8597e-08</ixy>
          <ixz>-1.3884e-08</ixz>
          <iyy>0.0010487</iyy>
          <iyz>5.2358e-12</iyz>
          <izz>0.0011932</izz>
        </inertia>
      </inertial>
      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
    </link>
    <joint name='1' type='revolute'>
      <pose relative_to='base_link'>0 0 0.12371 0 -0 0</pose>
      <parent>base_link</parent>
      <child>link1</child>
      <axis>
        <xyz>0 0 -1</xyz>
        <limit>
          <lower>0</lower>
          <upper>6.2832</upper>
          <effort>0</effort>
          <velocity>0</velocity>
        </limit>
        <dynamics>
          <spring_reference>0</spring_reference>
          <spring_stiffness>0</spring_stiffness>
        </dynamics>
      </axis>
    </joint>
    <link name='link1'>
      <pose relative_to='1'>0 0 0 0 -0 0</pose>
      <inertial>
        <pose>-0.004547 -0.002811 -0.030271 0 -0 0</pose>
        <mass>0.089464</mass>
        <inertia>
          <ixx>2.8404e-05</ixx>
          <ixy>1.2197e-08</ixy>
          <ixz>6.0756e-06</ixz>
          <iyy>2.686e-05</iyy>
          <iyz>-2.1814e-08</iyz>
          <izz>2.493e-05</izz>
        </inertia>
      </inertial>
      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
    </link>
    <joint name='2' type='revolute'>
      <pose relative_to='link1'>-0.019 0 0 1.5708 -0 -3.14159</pose>
      <parent>link1</parent>
      <child>link2</child>
      <axis>
        <xyz>0 0 1</xyz>
        <limit>
          <lower>0</lower>
          <upper>3.662</upper>
          <effort>0</effort>
          <velocity>0</velocity>
        </limit>
        <dynamics>
          <spring_reference>0</spring_reference>
          <spring_stiffness>0</spring_stiffness>
        </dynamics>
      </axis>
    </joint>
    <link name='link2'>
      <pose relative_to='2'>0 0 0 0 -0 0</pose>
      <inertial>
        <pose>0.13073 0 0.002719 0 -0 0</pose>
        <mass>0.8789</mass>
        <inertia>
          <ixx>0.00021808</ixx>
          <ixy>3.8197e-08</ixy>
          <ixz>-6.9356e-19</ixz>
          <iyy>0.0010335</iyy>
          <iyz>-8.1073e-16</iyz>
          <izz>0.0011036</izz>
        </inertia>
      </inertial>
      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
    </link>
    <joint name='3' type='revolute'>
      <pose relative_to='link2'>0.264 0 0 -3.14159 -0 2.8783</pose>
      <parent>link2</parent>
      <child>link3</child>
      <axis>
        <xyz>0 0 -1</xyz>
        <limit>
          <lower>-3.1416</lower>
          <upper>0</upper>
          <effort>0</effort>
          <velocity>0</velocity>
        </limit>
        <dynamics>
          <spring_reference>0</spring_reference>
          <spring_stiffness>0</spring_stiffness>
        </dynamics>
      </axis>
    </joint>
    <link name='link3'>
      <pose relative_to='3'>0 0 0 0 -0 0</pose>
      <inertial>
        <pose>0.1195 0.023882 -0.001697 0 -0 0</pose>
        <mass>0.71598</mass>
        <inertia>
          <ixx>0.00028128</ixx>
          <ixy>0.00016388</ixy>
          <ixz>-1.4389e-06</ixz>
          <iyy>0.00089643</iyy>
          <iyz>3.8117e-07</iyz>
          <izz>0.0010603</izz>
        </inertia>
      </inertial>
      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
    </link>
    <joint name='4' type='revolute'>
      <pose relative_to='link3'>0.23148 0 0 0 0 -0.26332</pose>
      <parent>link3</parent>
      <child>link4</child>
      <axis>
        <xyz>0 0 -1</xyz>
        <limit>
          <lower>-1.5708</lower>
          <upper>1.5708</upper>
          <effort>0</effort>
          <velocity>0</velocity>
        </limit>
        <dynamics>
          <spring_reference>0</spring_reference>
          <spring_stiffness>0</spring_stiffness>
        </dynamics>
      </axis>
    </joint>
    <link name='link4'>
      <pose relative_to='4'>0 0 0 0 -0 0</pose>
      <inertial>
        <pose>0.052533 0.038815 0.000501 0 -0 0</pose>
        <mass>0.23515</mass>
        <inertia>
          <ixx>7.9691e-05</ixx>
          <ixy>2.9447e-10</ixy>
          <ixz>-4.225e-08</ixz>
          <iyy>9.4211e-05</iyy>
          <iyz>-6.849e-08</iyz>
          <izz>6.8988e-05</izz>
        </inertia>
      </inertial>
      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
    </link>
    <joint name='5' type='revolute'>
      <pose relative_to='link4'>0.075 -0.0015 -0.0015 -1.57079 -1.57079 -3.14159</pose>
      <parent>link4</parent>
      <child>link5</child>
      <axis>
        <xyz>0 0 -1</xyz>
        <limit>
          <lower>-1.5708</lower>
          <upper>1.5708</upper>
          <effort>0</effort>
          <velocity>0</velocity>
        </limit>
        <dynamics>
          <spring_reference>0</spring_reference>
          <spring_stiffness>0</spring_stiffness>
        </dynamics>
      </axis>
    </joint>
    <link name='link5'>
      <pose relative_to='5'>0 0 0 0 -0 0</pose>
      <inertial>
        <pose>1e-05 -0.016598 -0.009317 0 -0 0</pose>
        <mass>0.16797</mass>
        <inertia>
          <ixx>4.8034e-05</ixx>
          <ixy>6.849e-08</ixy>
          <ixz>2.7193e-08</ixz>
          <iyy>6.7289e-05</iyy>
          <iyz>2.9447e-10</iyz>
          <izz>4.812e-05</izz>
        </inertia>
      </inertial>
      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
    </link>
    <joint name='6' type='revolute'>
      <pose relative_to='link5'>0 -0.036 0 1.5708 -0 0</pose>
      <parent>link5</parent>
      <child>link6</child>
      <axis>
        <xyz>0 0 -1</xyz>
        <limit>
          <lower>-3.1416</lower>
          <upper>3.1416</upper>
          <effort>0</effort>
          <velocity>0</velocity>
        </limit>
        <dynamics>
          <spring_reference>0</spring_reference>
          <spring_stiffness>0</spring_stiffness>
        </dynamics>
      </axis>
    </joint>
    <link name='link6'>
      <pose relative_to='6'>0 0 0 0 -0 0</pose>
      <inertial>
        <pose>-3.5e-05 0.014495 0.063655 0 -0 0</pose>
        <mass>0.33362</mass>
        <inertia>
          <ixx>0.00020137</ixx>
          <ixy>9.5443e-08</ixy>
          <ixz>6.8488e-08</ixz>
          <iyy>0.00016983</iyy>
          <iyz>-3.2415e-06</iyz>
          <izz>0.00025638</izz>
        </inertia>
      </inertial>
      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
    </link>
  </model>
</sdf>

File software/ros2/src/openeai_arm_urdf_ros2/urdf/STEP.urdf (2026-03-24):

<?xml version="1.0" encoding="utf-8"?>
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
<robot name="STEP">
  <link name="base_link">
    <inertial>
      <origin xyz="-2.286E-05 2.7497E-09 0.01623" rpy="0 0 0" />
      <mass value="0.50446" />
      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
    </inertial>
    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
  </link>
  <link name="link1">
    <inertial>
      <origin xyz="-0.0045469 -0.0028108 -0.030271" rpy="0 0 0" />
      <mass value="0.419464" />
      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
    </inertial>
    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
  </link>
  <joint name="1" type="revolute">
    <origin xyz="0 0 0.12371" rpy="0 0 0" />
    <parent link="base_link" />
    <child link="link1" />
    <axis xyz="0 0 1" />
    <limit lower="-1.57" upper="1.57" effort="0" velocity="0" />
  </joint>
  <link name="link2">
    <inertial>
      <origin xyz="0.13073 1.5099E-12 0.0027189" rpy="0 0 0" />
      <mass value="1.5389" />
      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
    </inertial>
    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
  </link>
  <joint name="2" type="revolute">
    <origin xyz="-0.019 0 0" rpy="1.5708 0 3.1416" />
    <parent link="link1" />
    <child link="link2" />
    <axis xyz="0 0 1" />
    <limit lower="-0.2" upper="3.662" effort="0" velocity="0" />
  </joint>
  <link name="link3">
    <inertial>
      <origin xyz="0.1657 0.017535 -0.0016971" rpy="0 0 0" />
      <mass value="1.01598" />
      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
    </inertial>
    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
  </link>
  <joint name="3" type="revolute">
    <origin xyz="0.264 0 0" rpy="3.1416 0 2.8783" />
    <parent link="link2" />
    <child link="link3" />
    <axis xyz="0 0 1" />
    <limit lower="-0.1" upper="3.1416" effort="0" velocity="0" />
  </joint>
  <link name="link4">
    <inertial>
      <origin xyz="0.052533 0.038815 -0.041806" rpy="0 0 0" />
      <mass value="0.53515" />
      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
    </inertial>
    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
  </link>
  <joint name="4" type="revolute">
    <origin xyz="0.23148 0 0" rpy="0 0 -0.26332" />
    <parent link="link3" />
    <child link="link4" />
    <axis xyz="0 0 1" />
    <limit lower="-1.5708" upper="1.5708" effort="0" velocity="0" />
  </joint>
  <link name="link5">
    <inertial>
      <origin xyz="1.0201E-05 -0.016598 -0.0033441" rpy="0 0 0" />
      <mass value="0.46797" />
      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
    </inertial>
    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
  </link>
  <joint name="5" type="revolute">
    <origin xyz="0.075 -0.0015 -0.0015" rpy="1.5708 -1.5708 0" />
    <parent link="link4" />
    <child link="link5" />
    <axis xyz="0 0 1" />
    <limit lower="-1.5708" upper="1.5708" effort="0" velocity="0" />
  </joint>
  <link name="link6">
    <inertial>
      <origin xyz="-3.4881E-05 0.014495 0.054359" rpy="0 0 0" />
      <mass value="0.83362" />
      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
    </inertial>
    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
  </link>
  <joint name="6" type="revolute">
    <origin xyz="0 -0.036 0" rpy="1.5708 0 0" />
    <parent link="link5" />
    <child link="link6" />
    <axis xyz="0 0 1" />
    <limit lower="-3.1416" upper="3.1416" effort="0" velocity="0" />
  </joint>
</robot>

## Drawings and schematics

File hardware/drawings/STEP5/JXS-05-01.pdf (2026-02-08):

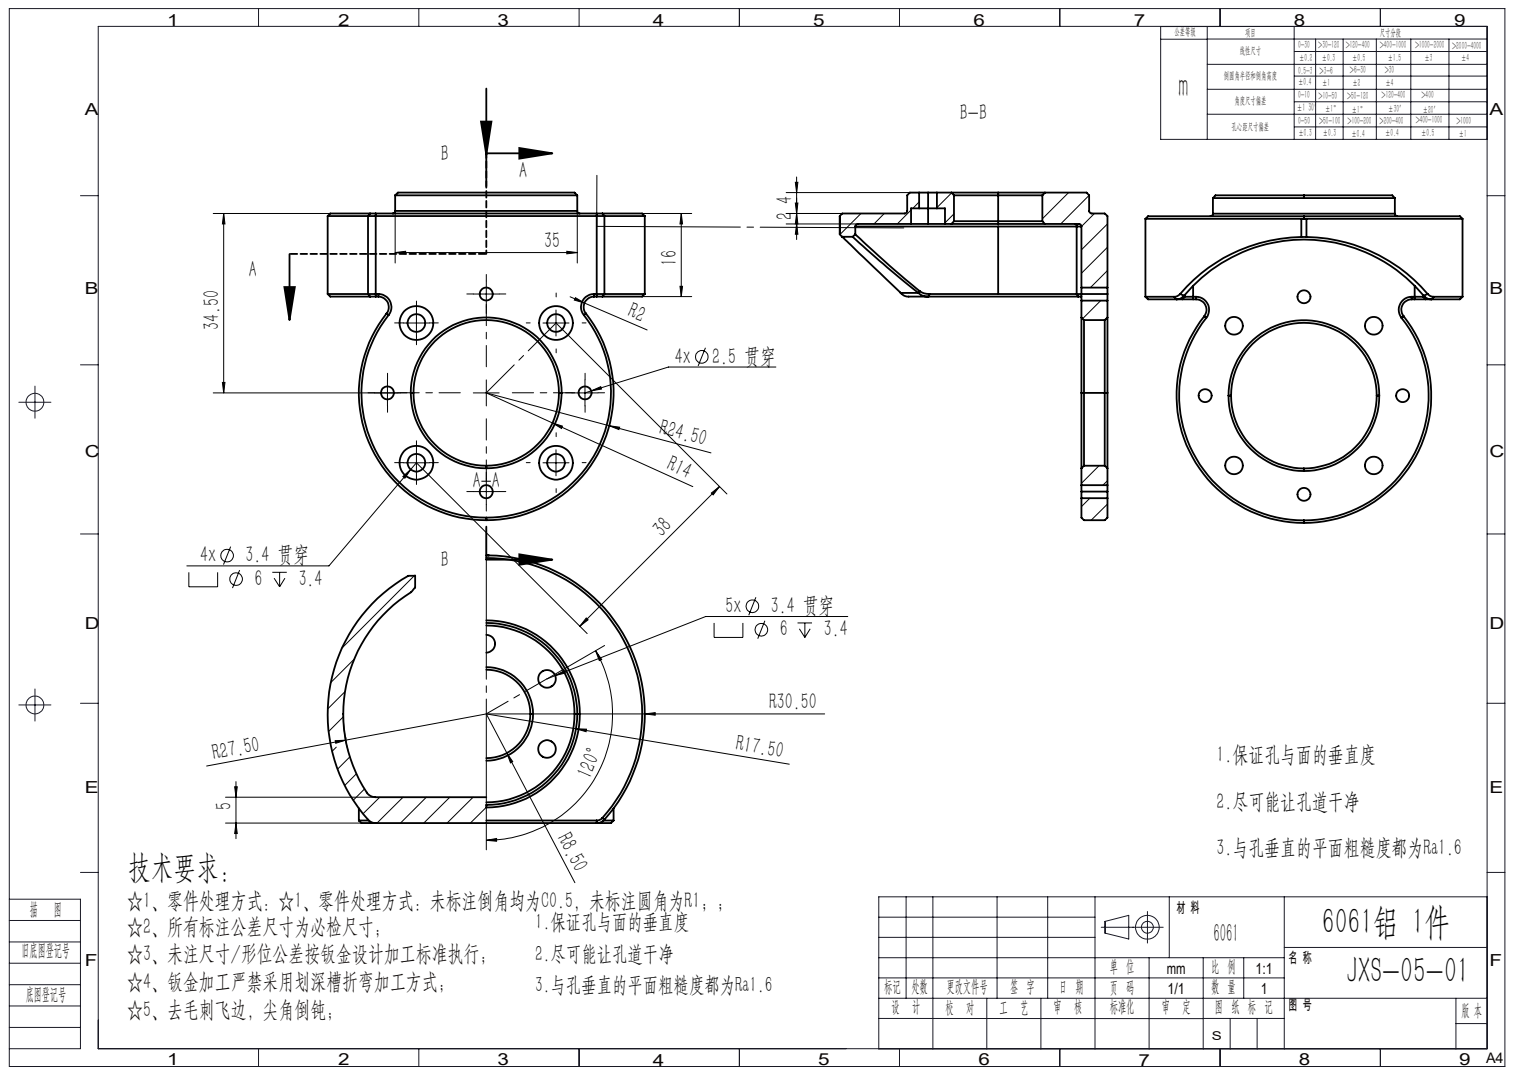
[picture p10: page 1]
JXS-05-01 标记 处数 更改文件号; 标准化; 角度尺寸偏差 m 倒圆角半径和倒角高度; ±4 线性尺寸

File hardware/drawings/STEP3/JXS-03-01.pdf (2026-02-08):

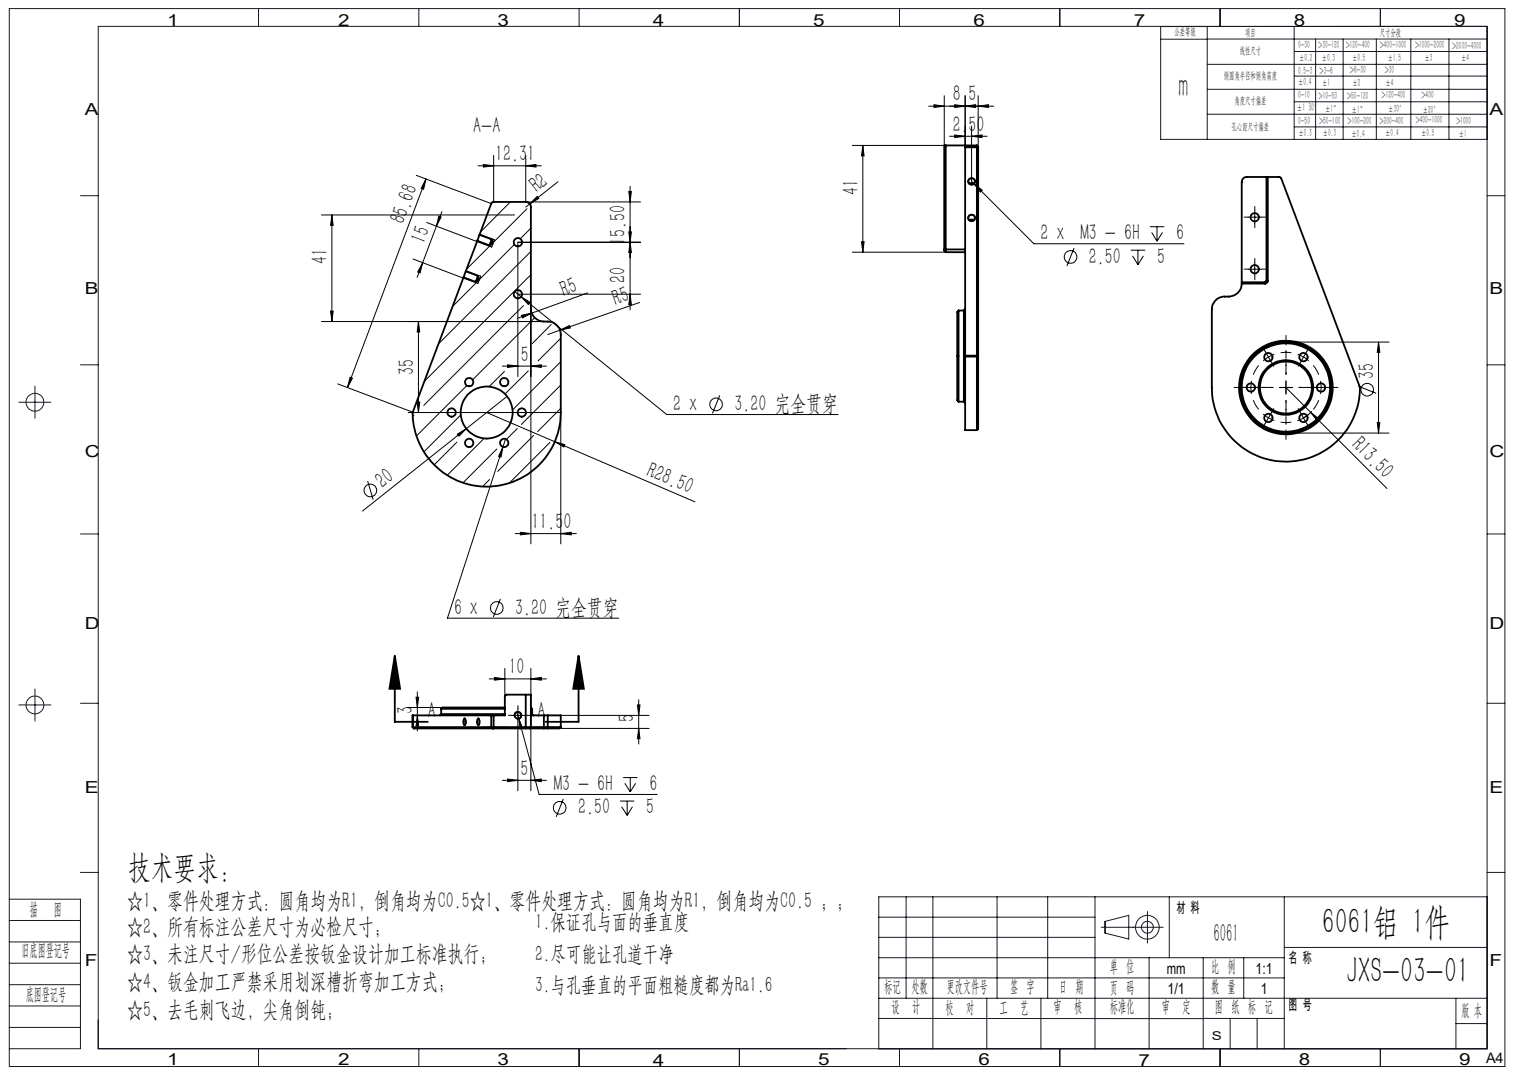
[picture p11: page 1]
3.20 完全贯穿; JXS-03-01 标记 处数 更改文件号; 标准化; 角度尺寸偏差 m 倒圆角半径和倒角高度; ±4 线性尺寸; ☆1、零件处理方式：圆角均为R1，倒角均为C0.5☆1、零件处理方式：圆角均为R1，倒角均为C0.5 ；；

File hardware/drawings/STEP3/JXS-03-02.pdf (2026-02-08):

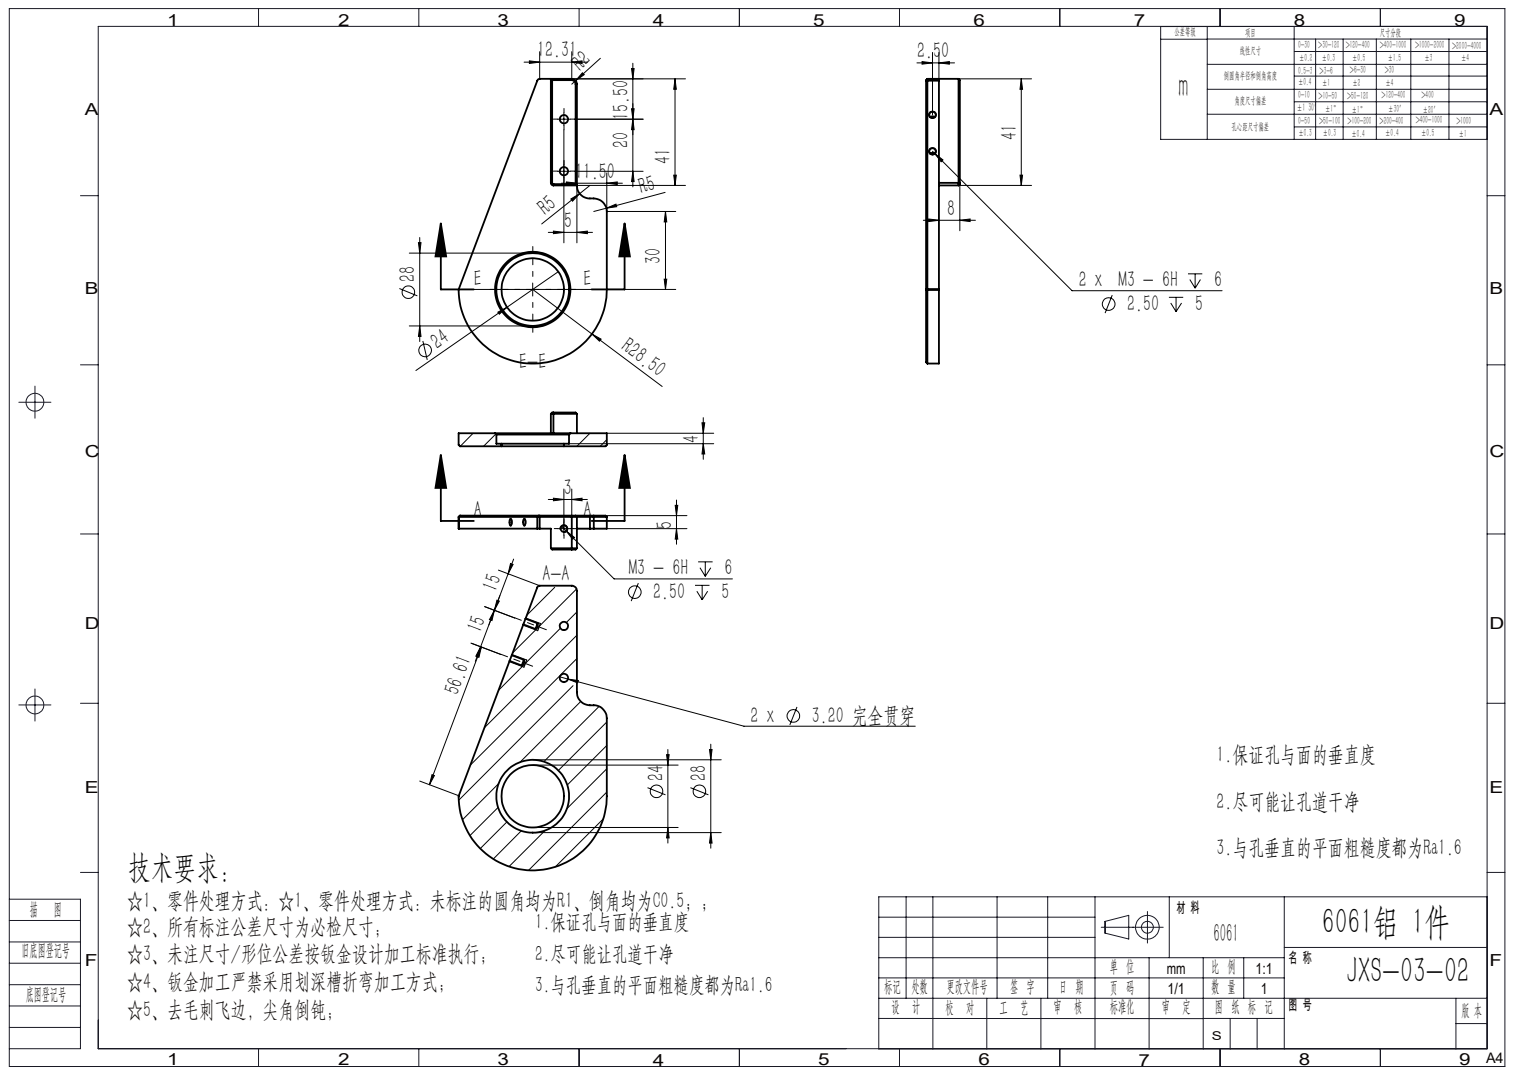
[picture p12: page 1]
3.20 完全贯穿; JXS-03-02 标记 处数 更改文件号; 标准化; 角度尺寸偏差 m 倒圆角半径和倒角高度; ±4 线性尺寸

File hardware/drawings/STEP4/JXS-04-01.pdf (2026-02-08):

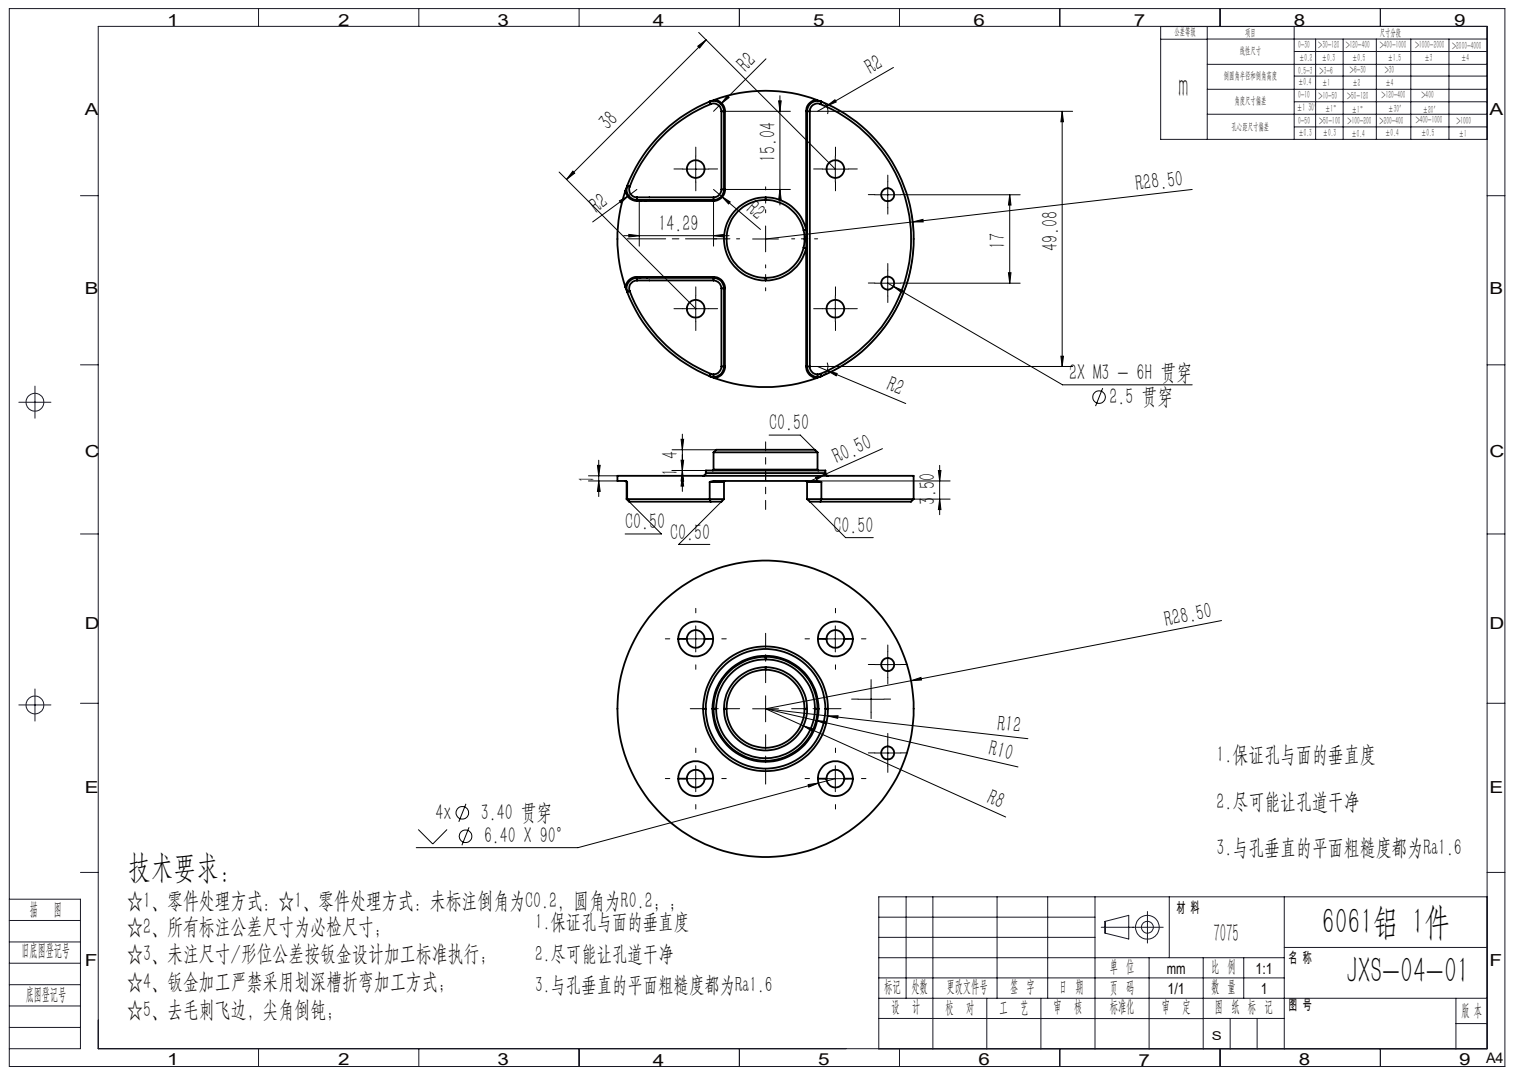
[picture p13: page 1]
JXS-04-01 标记 处数 更改文件号; 标准化; 角度尺寸偏差 m 倒圆角半径和倒角高度; ±4 线性尺寸

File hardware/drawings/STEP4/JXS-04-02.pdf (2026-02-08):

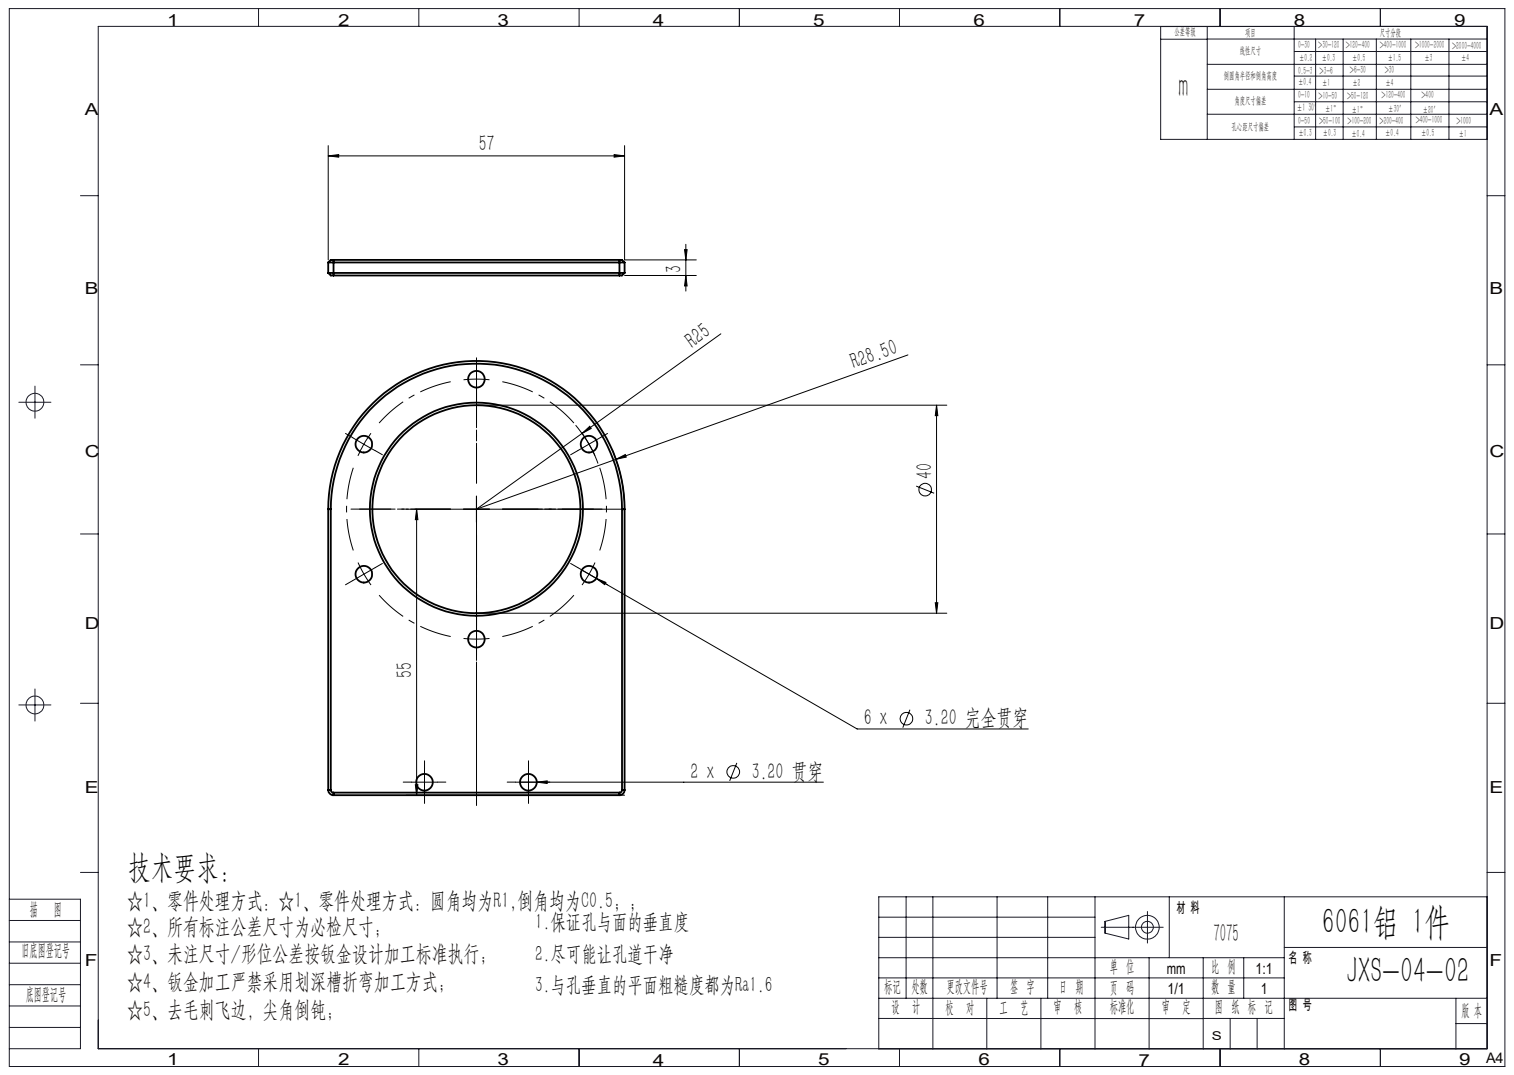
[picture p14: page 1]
3.20 完全贯穿; JXS-04-02 标记 处数 更改文件号; 标准化; 角度尺寸偏差 m 倒圆角半径和倒角高度; ±4 线性尺寸

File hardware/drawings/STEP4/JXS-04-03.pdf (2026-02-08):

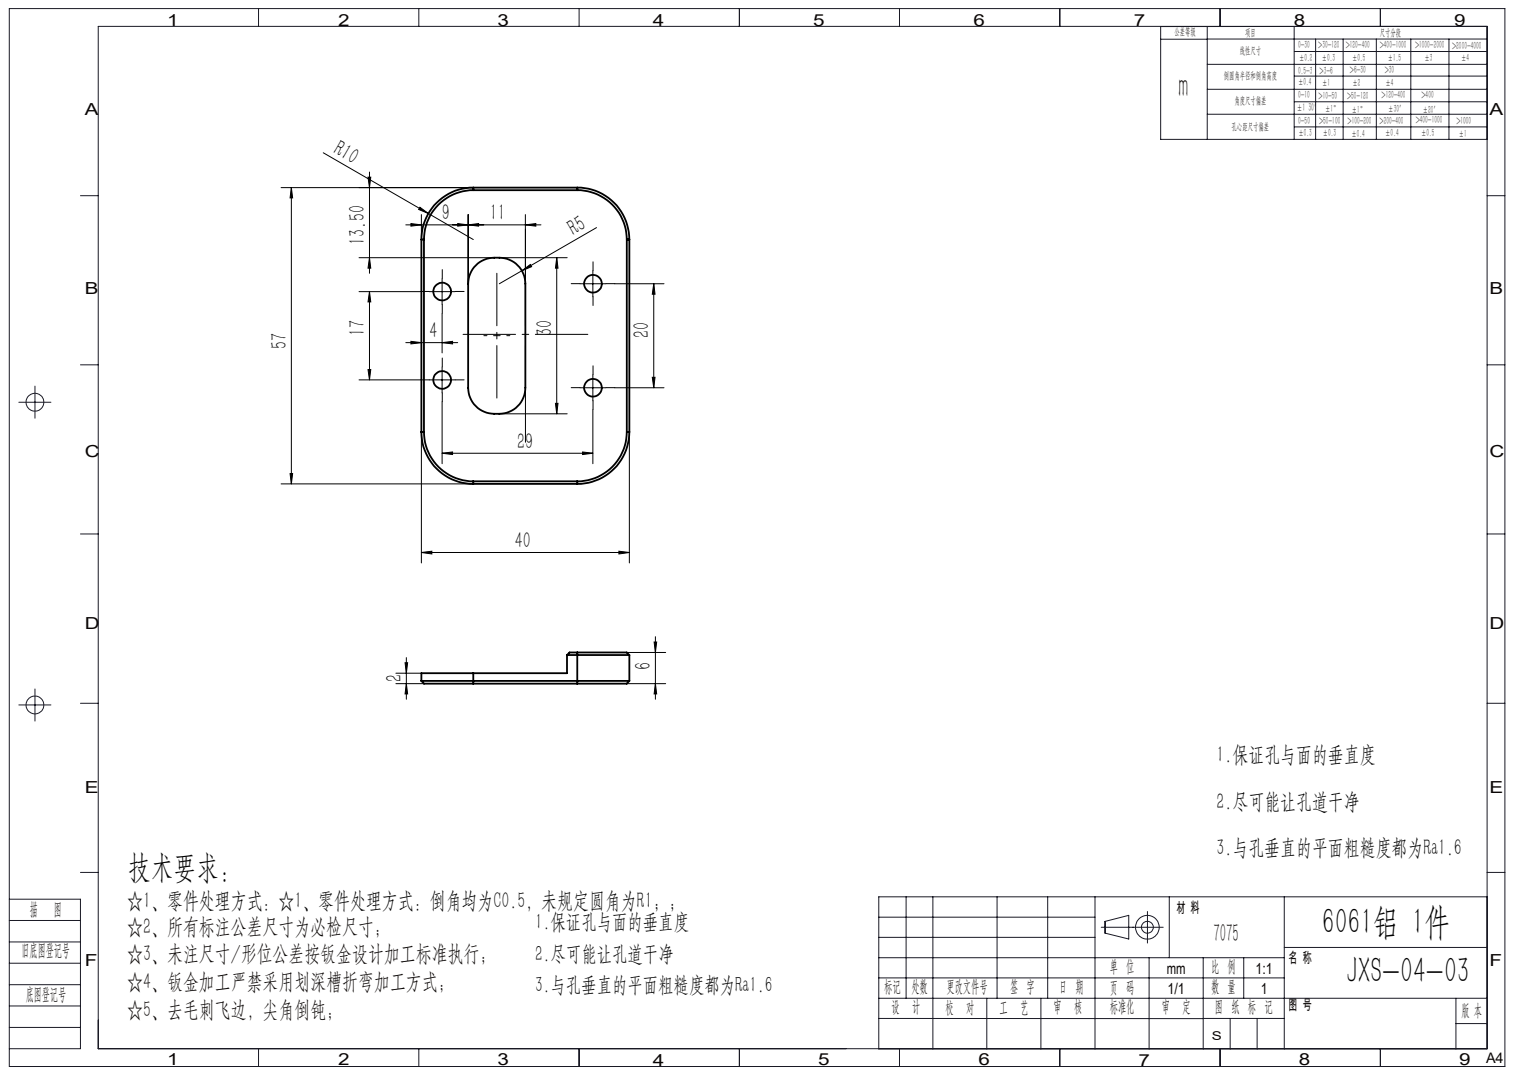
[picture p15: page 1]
JXS-04-03 标记 处数 更改文件号; 标准化; 角度尺寸偏差 m 倒圆角半径和倒角高度; ±4 线性尺寸

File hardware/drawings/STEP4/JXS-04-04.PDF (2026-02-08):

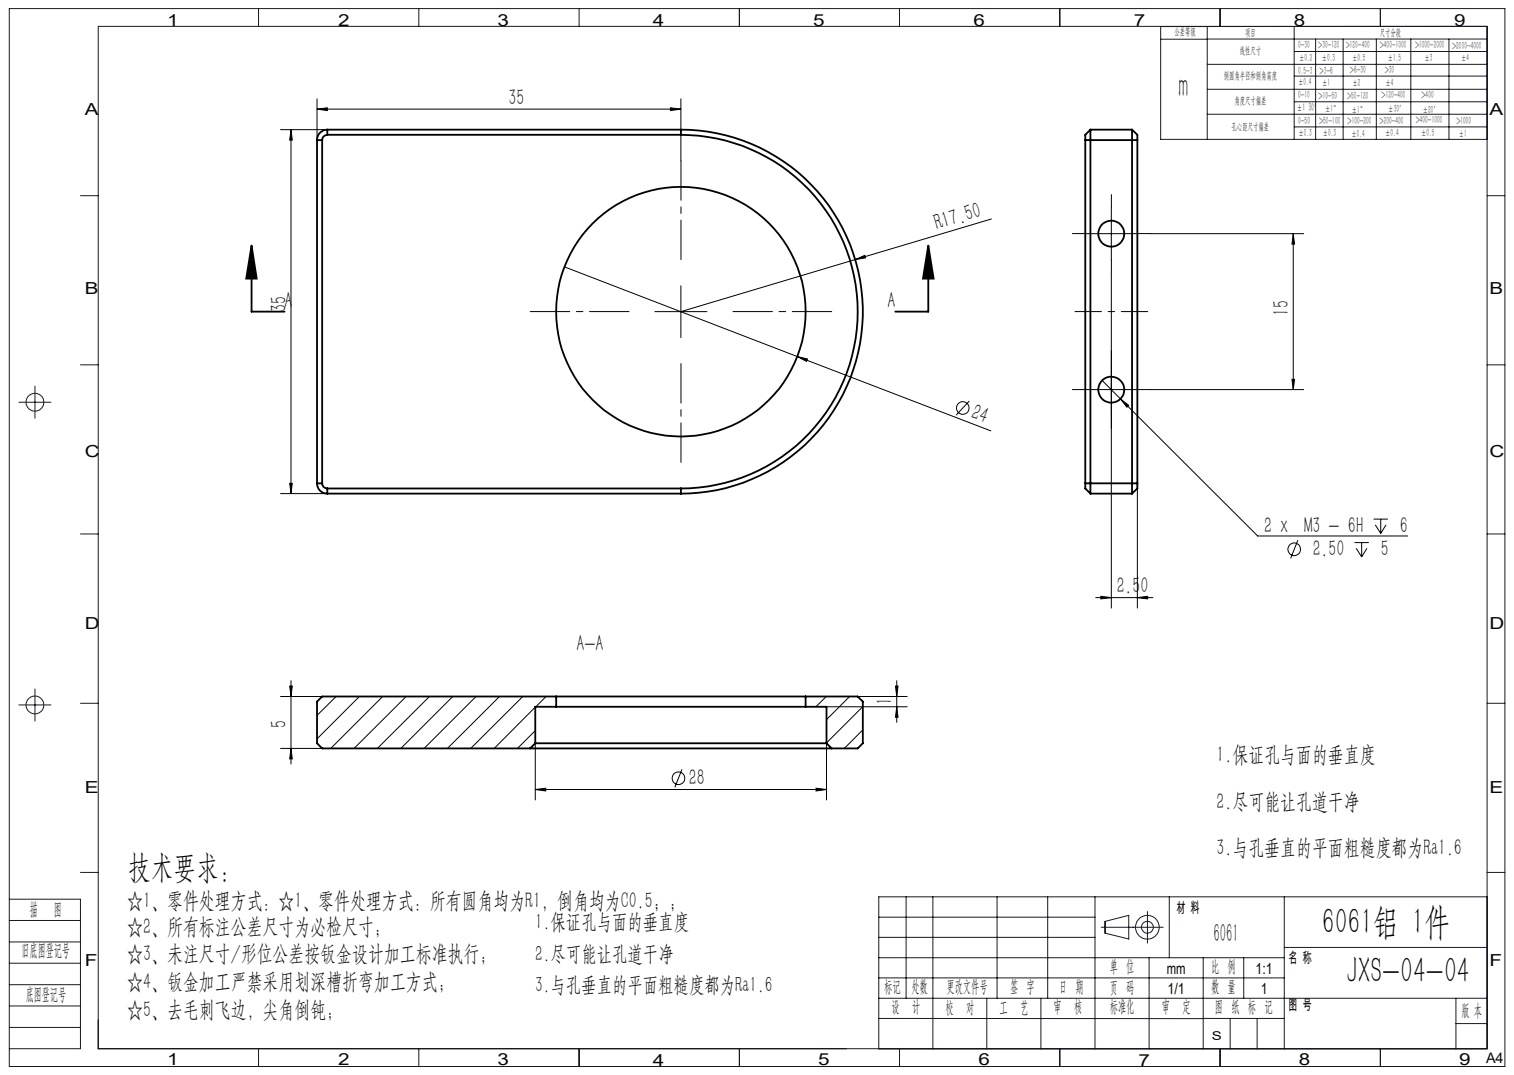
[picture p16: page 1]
JXS-04-04 标记 处数 更改文件号; 标准化; 角度尺寸偏差 m 倒圆角半径和倒角高度; ±4 线性尺寸

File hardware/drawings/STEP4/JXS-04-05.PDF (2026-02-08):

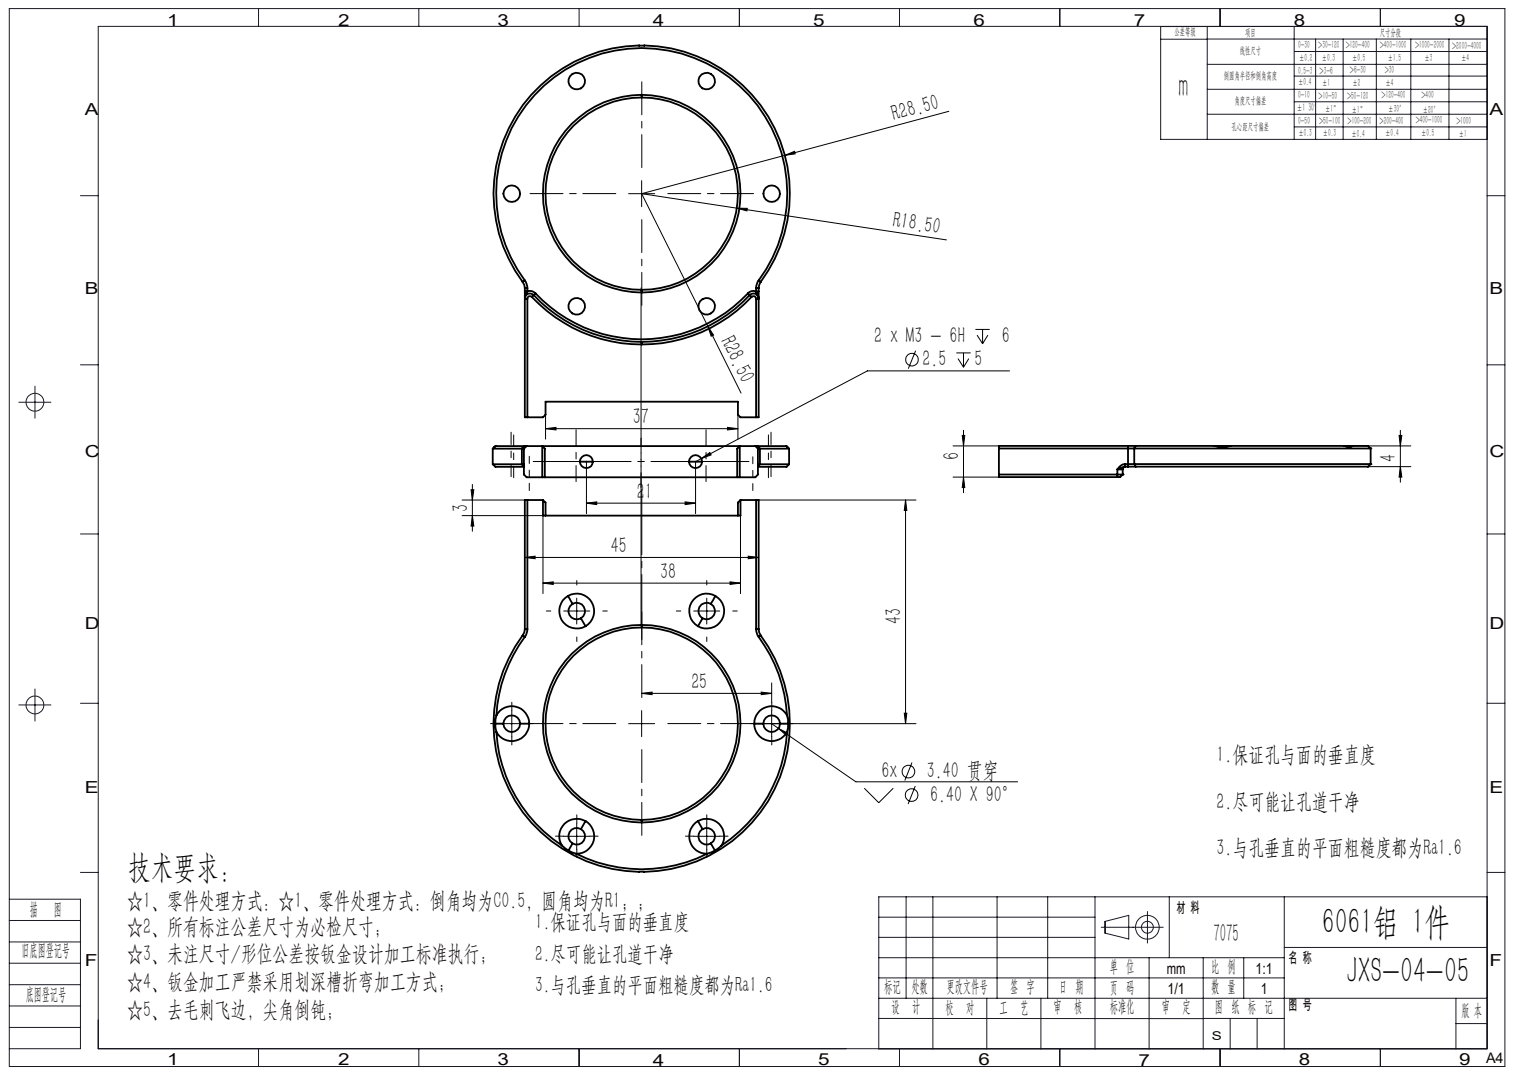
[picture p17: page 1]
JXS-04-05 标记 处数 更改文件号; 标准化; 角度尺寸偏差 m 倒圆角半径和倒角高度; ±4 线性尺寸

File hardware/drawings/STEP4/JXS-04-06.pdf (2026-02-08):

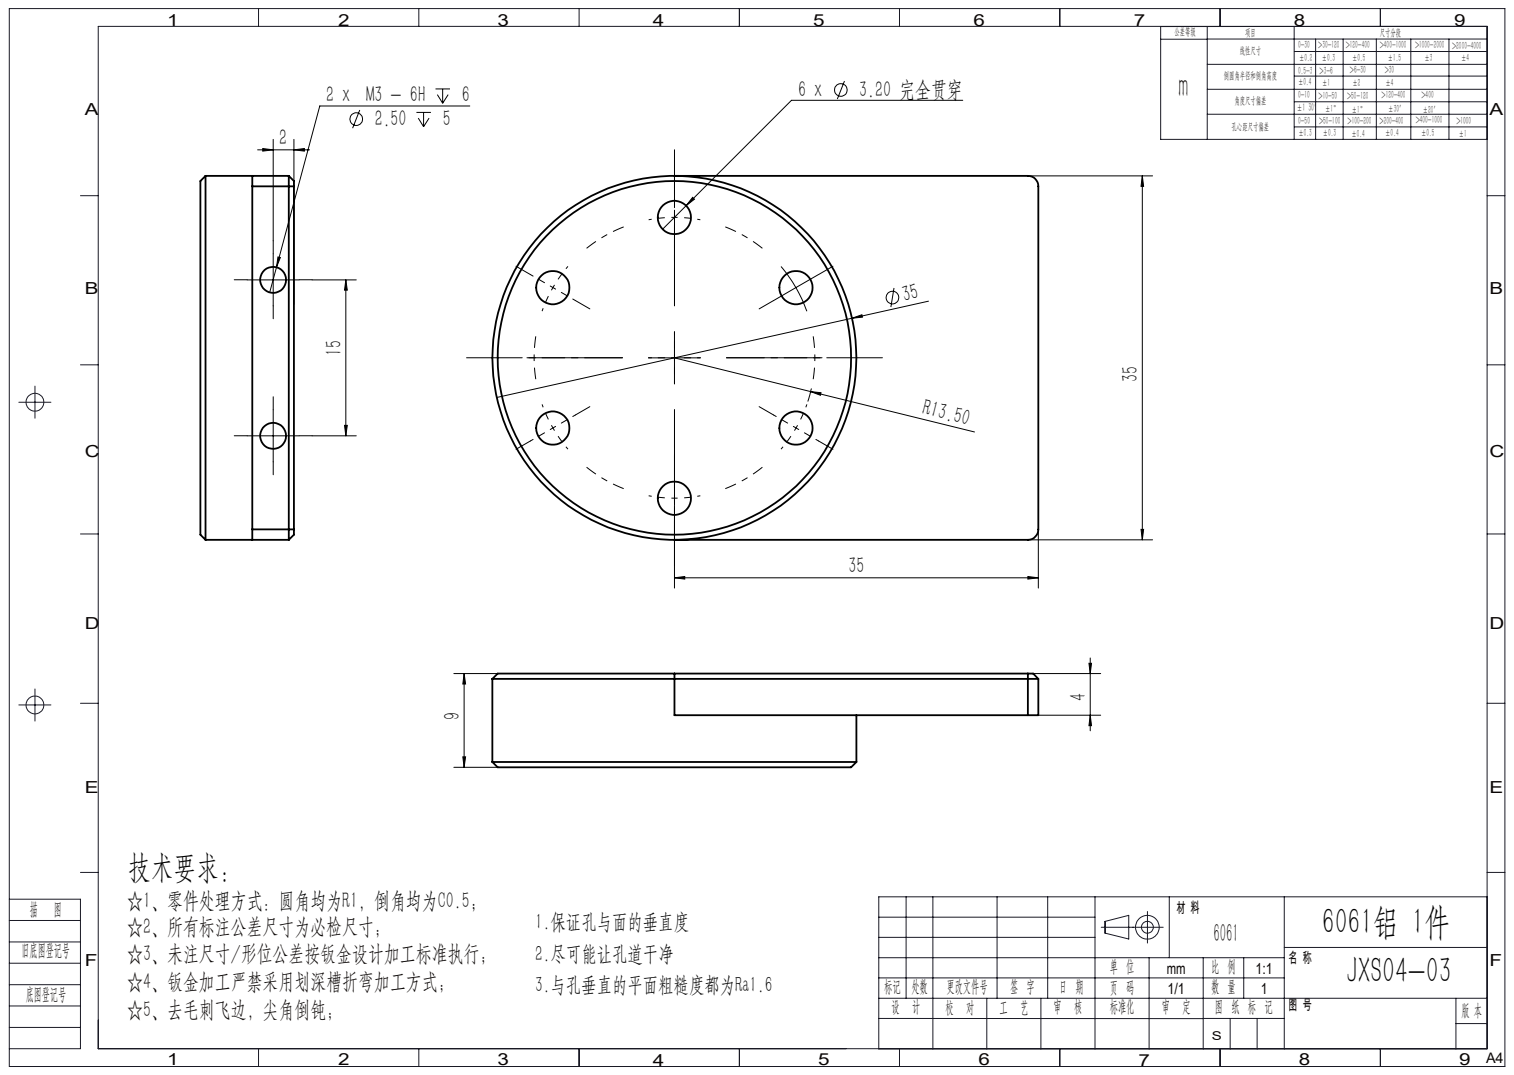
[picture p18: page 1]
3.20 完全贯穿; JXS04-03 标记 处数 更改文件号; 标准化; 角度尺寸偏差 m 倒圆角半径和倒角高度; ±4 线性尺寸

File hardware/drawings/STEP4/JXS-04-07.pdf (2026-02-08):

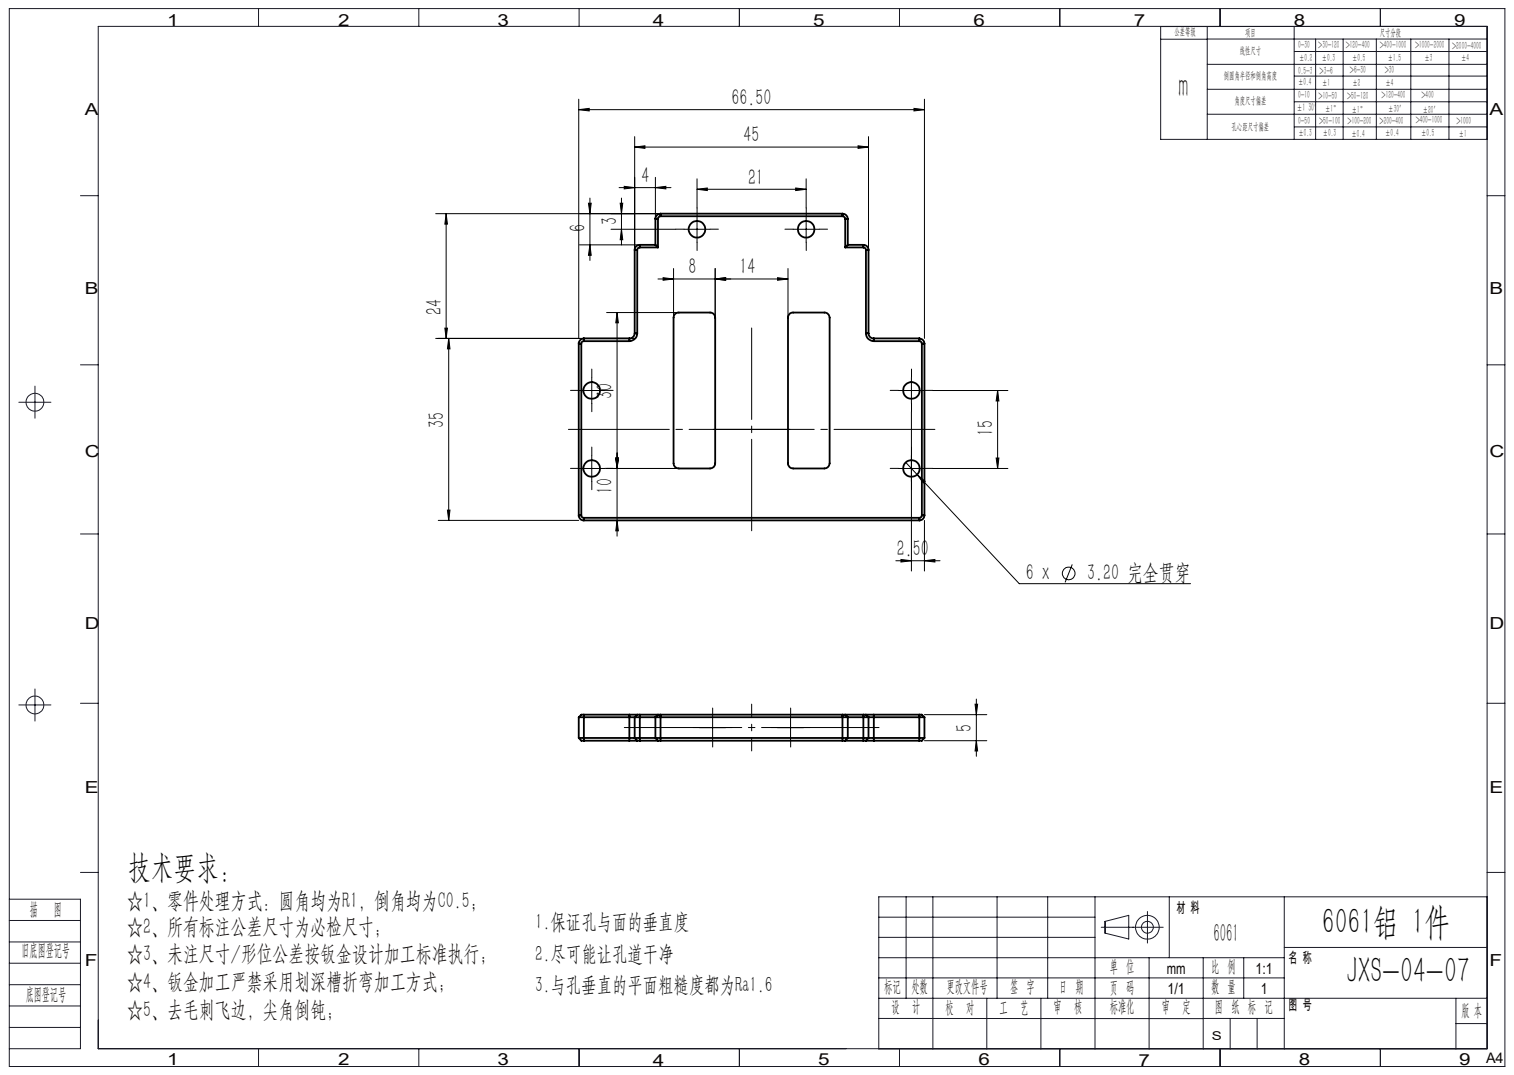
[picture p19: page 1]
3.20 完全贯穿; JXS-04-07 标记 处数 更改文件号; 标准化; 角度尺寸偏差 m 倒圆角半径和倒角高度; ±4 线性尺寸

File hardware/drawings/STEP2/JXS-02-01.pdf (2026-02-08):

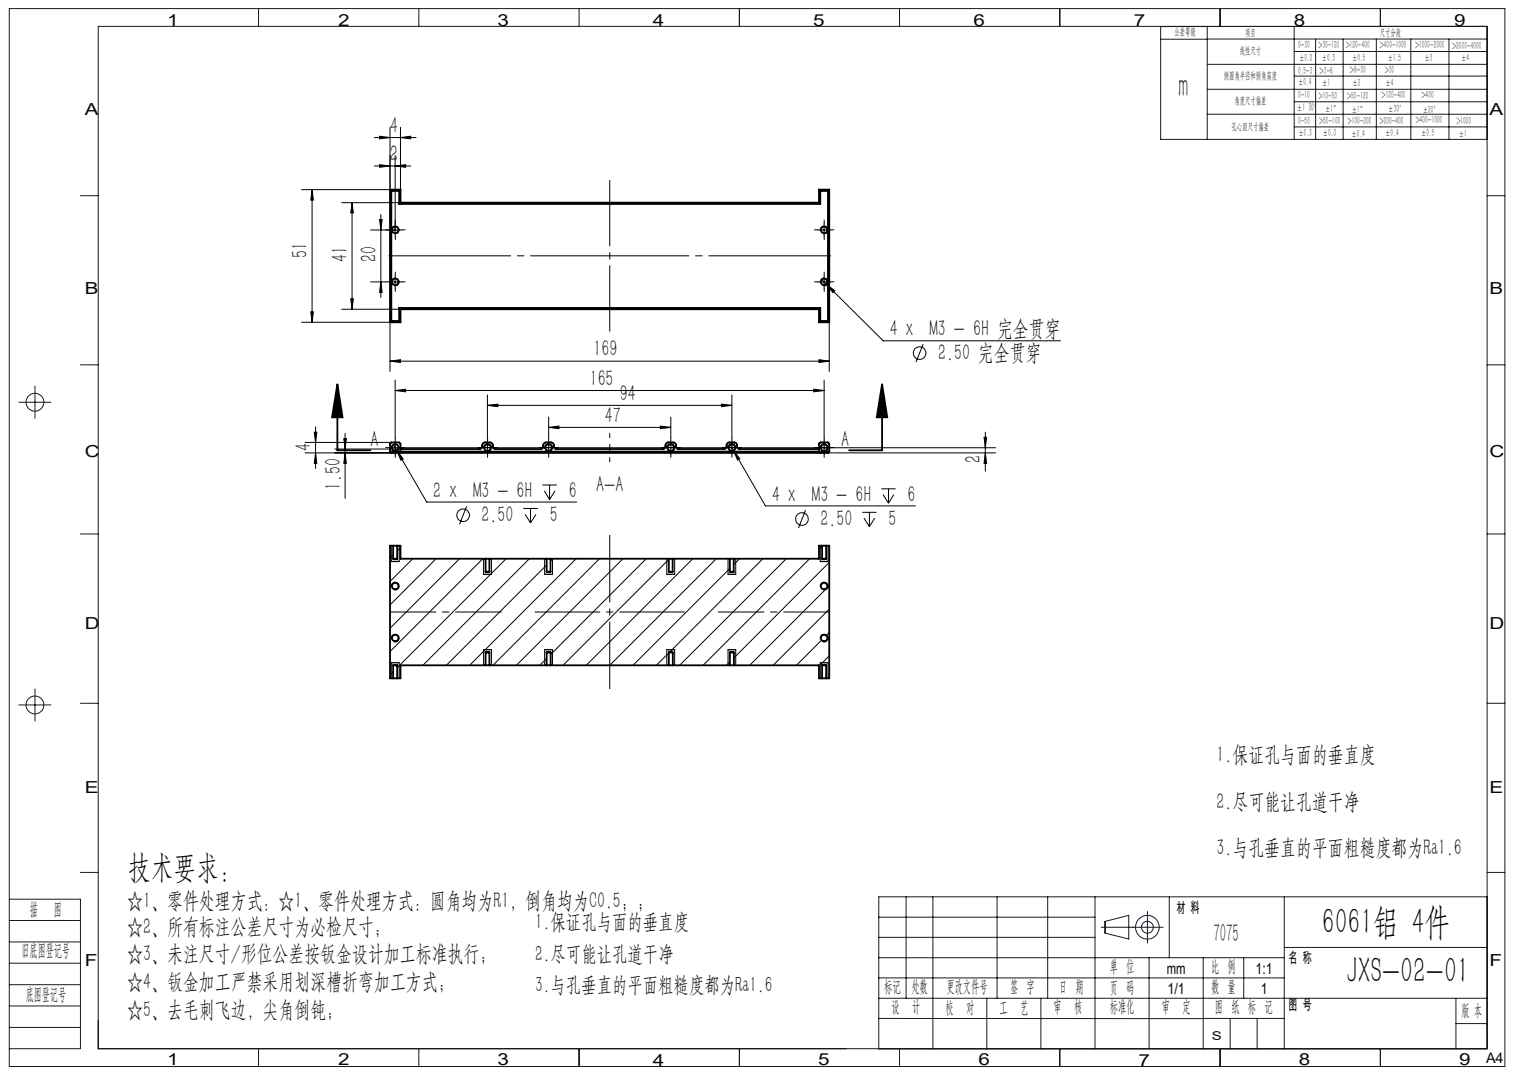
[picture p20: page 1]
4 x M3 - 6H 完全贯穿; 2.50 完全贯穿; JXS-02-01 标记 处数 更改文件号; 标准化; 角度尺寸偏差 m 倒圆角半径和倒角高度; ±4 线性尺寸

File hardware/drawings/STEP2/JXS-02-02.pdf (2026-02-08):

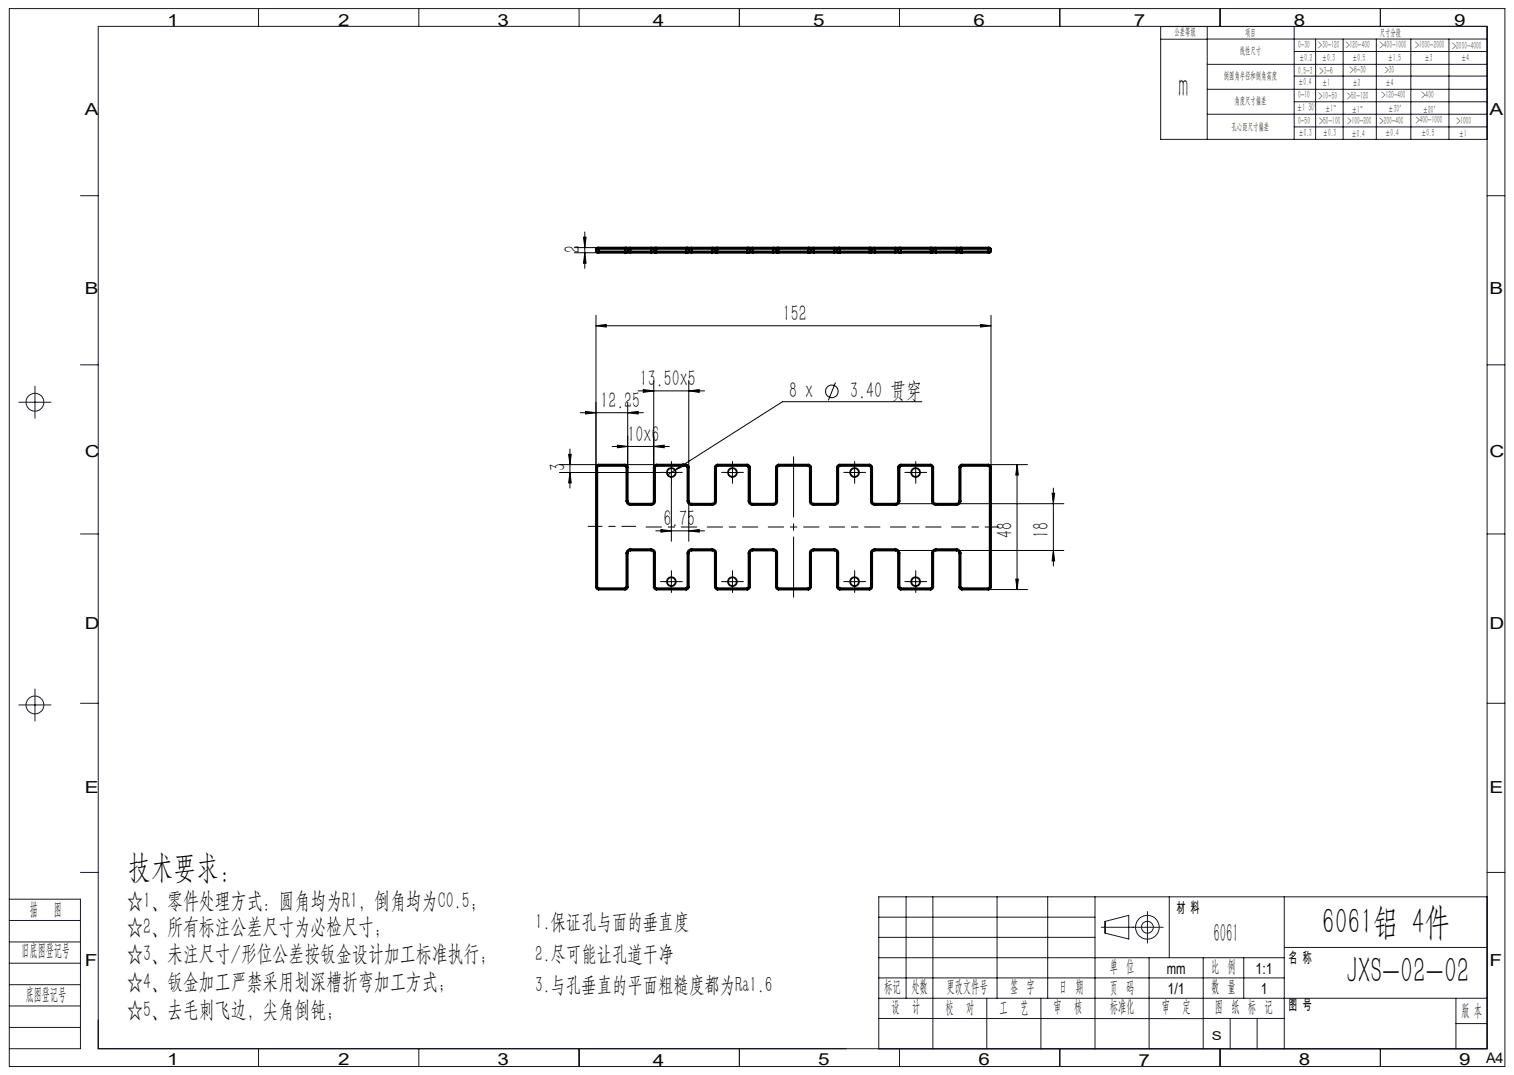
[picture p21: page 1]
JXS-02-02 标记 处数 更改文件号; 标准化; 角度尺寸偏差 m 倒圆角半径和倒角高度; ±4 线性尺寸

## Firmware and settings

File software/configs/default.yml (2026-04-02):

can_config: 
  id: /dev/ttyACM0
  baud_rate: 921600

urdf:
  path: ros2/src/openeai_arm_urdf_ros2/urdf/STEP.urdf
  base_link: base_link
  ee_link: link6

controller:
  interpolation: minjerk
  filter_alpha: 0.9
  enable_safety_check: false
  drag_stationary_vel_threshold: 0.2

motors:
  - name: joint_1
    type: DM4340
    slave_id: 0x02
    master_id: 0x12
    min_position: -3.14
    max_position: 3.14
    reset_pose: 0.11
    dynamic_coefficients:
      kp: 300.0
      ki: 0.0
      kd: 5.0
      friction: 1.0
      friction_alpha: 50.0
      drag:
        stationary_kp: 10.0
        stationary_kd: 0.0
        moving_kd: -0.2
        moving_tanh: 0.5
        moving_tanh_alpha: 2.0
  - name: joint_2
    type: DM4340
    slave_id: 0x01
    master_id: 0x11
    min_position: -3.14
    max_position: 3.14
    reset_pose: -1.36
    dynamic_coefficients:
      kp: 300.0
      ki: 0.0
      kd: 5.0
      friction: 1.0
      friction_alpha: 50.0
      drag:
        stationary_kp: 30.0
        stationary_kd: 2.5
        moving_kd: -0.2
        moving_tanh: 0.4
        moving_tanh_alpha: 2.0
  - name: joint_3
    type: DM4340
    slave_id: 0x03
    master_id: 0x13
    min_position: -3.14
    max_position: 3.14
    reset_pose: -0.18
    dynamic_coefficients:
      kp: 300.0
      ki: 0.0
      kd: 5.0
      friction: 1.0
      friction_alpha: 50.0
      drag:
        stationary_kp: 10.0
        stationary_kd: 0.5
        moving_kd: -0.2
        moving_tanh: 0.4
        moving_tanh_alpha: 2.0
  - name: joint_4
    type: DM4310
    slave_id: 0x04
    master_id: 0x14
    min_position: -3.14
    max_position: 3.14
    reset_pose: 0.19
    dynamic_coefficients:
      kp: 50.0
      ki: 0.0
      kd: 0.5
      friction: 0.5
      friction_alpha: 5.0
      drag:
        stationary_kp: 2.5
        stationary_kd: 0.5
        moving_kd: 0.0
        moving_tanh: 0.0
        moving_tanh_alpha: 0.0
  - name: joint_5
    type: DM4310
    slave_id: 0x05
    master_id: 0x15
    min_position: -3.14
    max_position: 3.14
    reset_pose: -1.46
    dynamic_coefficients:
      kp: 20.0
      ki: 0.0
      kd: 0.1
      friction: 0.5
      friction_alpha: 5.0
      drag:
        stationary_kp: 2.5
        stationary_kd: 0.5
        moving_kd: 0.0
        moving_tanh: 0.0
        moving_tanh_alpha: 0.0
  - name: joint_6
    type: DM4310
    slave_id: 0x06
    master_id: 0x16
    min_position: -3.14
    max_position: 3.14
    reset_pose: 1.93
    dynamic_coefficients:
      kp: 20.0
      ki: 0.0
      kd: 0.1
      friction: 0.5
      friction_alpha: 5.0
      drag:
        stationary_kp: 2.5
        stationary_kd: 0.5
        moving_kd: 0.0
        moving_tanh: 0.0
        moving_tanh_alpha: 0.0
  - name: joint_7
    type: DM4310
    slave_id: 0x07
    master_id: 0x17
    min_position: 0.0
    max_position: 1.35
    reset_pose: -2.26
    dynamic_coefficients:
      kp: 0.0
      ki: 0.0
      kd: 0.1
      friction: 2.0
      friction_alpha: 5.0
      drag:
        stationary_kp: 5.0
        stationary_kd: 0.1
        moving_kd: 0.1
        moving_tanh: 0.2
        moving_tanh_alpha: 25.0
      
      

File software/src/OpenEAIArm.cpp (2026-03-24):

#include "OpenEAIArm.hpp"

std::ostream& operator<<(std::ostream& os, const OpenEAIArm::JointArray& arr) {
    os << "[";
    for (size_t i = 0; i < arr.size(); ++i) {
        os << arr[i];
        if (i != arr.size()-1) os << ", ";
    }
    os << "]";
    return os;
}

/*
    * @description: Constructor that loads configuration from a file
    * @param config_path: Path to the configuration file
    * @param control_mode: Control mode for the arm
*/
OpenEAIArm::OpenEAIArm(const std::string& config_path, ControlMode control_mode): 
    mode_(control_mode)
{
    std::cout << "Loading config file from " << config_path << std::endl;
    config = load_arm_config(config_path);

    if (mode_ != ControlMode::SIM) {
        serial_ = std::make_shared<SerialPort>(config.can.id, config.can.baud_rate);
        motor_ctl_ = std::make_unique<DM_Motor::Motor_Control>(serial_);
    }


    for (size_t i = 0; i < NUM_JOINTS; ++i) {
        auto motor = config.motors[i];
        DM_Motor::DM_Motor_Type type = DM_Motor::DM4310;
        if (motor.type == "DM4340") type = DM_Motor::DM4340;
        else if (motor.type == "DM4310") type = DM_Motor::DM4310;
        DM_Motor::Motor* m = new DM_Motor::Motor(type, motor.slave_id, motor.master_id);
        motors_[i] = m;
        if (mode_ != ControlMode::SIM) {
            motor_ctl_->addMotor(m);
        }

        joint_names[i] = motor.name;
        joint_limits_low_[i] = motor.min_position;
        joint_limits_high_[i] = motor.max_position;
        reset_pose_[i] = motor.reset_pose;
        kp_[i] = motor.dynamic_coeff.kp;
        kd_[i] = motor.dynamic_coeff.kd;
        drag_stationary_kp_[i] = motor.dynamic_coeff.drag.stationary_kp;
        drag_stationary_kd_[i] = motor.dynamic_coeff.drag.stationary_kd;
        drag_moving_kd_[i] = motor.dynamic_coeff.drag.moving_kd;
        drag_moving_tanh_[i] = motor.dynamic_coeff.drag.moving_tanh;
        drag_moving_tanh_alpha_[i] = motor.dynamic_coeff.drag.moving_tanh_alpha;
    }

    drag_stationary_vel_threshold_ = config.controller.drag_stationary_vel_threshold;


    initialize_arm(true);

    std::cout << "OpenEAIArm initialized and ready." << std::endl;
}


void OpenEAIArm::initialize_arm(bool reinitialize_manager) {
    for (size_t i = 0; i < NUM_JOINTS; ++i) {
        if (mode_ != ControlMode::MIT_DRAG) {
            ki_[i] = config.motors[i].dynamic_coeff.ki;
            friction_[i] = config.motors[i].dynamic_coeff.friction;
            friction_alpha_[i] = config.motors[i].dynamic_coeff.friction_alpha;
        }
        else {
            ki_[i] = 0;
            friction_[i] = 0;
            friction_alpha_[i] = 0;
        }
    }

    std::string interpolation_method = config.controller.interpolation;
    MotorManager::InterpolationMethod mmim;
    if (interpolation_method == "linear") mmim = MotorManager::InterpolationMethod::Linear;
    else if (interpolation_method == "cubics") mmim = MotorManager::InterpolationMethod::CubicS;
    else mmim = MotorManager::InterpolationMethod::MinJerk;
    float mm_alpha = config.controller.filter_alpha;

    if (reinitialize_manager)  {
        if (mode_ != ControlMode::SIM)
            enable_all();

        if (manager_) manager_->stop();
        switch (mode_) {
            case ControlMode::MIT_MIX:
            case ControlMode::MIT_DRAG:
                manager_ = std::make_unique<MotorManager>(motors_, motor_ctl_.get(), mmim, mm_alpha);
                break;
            case ControlMode::SIM:
                manager_ = std::make_unique<SimMotorManager>(config.urdf.path, reset_pose_);
                break;
        }
        
        kd_solver = std::make_shared<KDSolver>(config.urdf.path, config.urdf.base_link, config.urdf.ee_link);
        
        float dt = manager_->getControlCycle();
        pid_controller = std::make_unique<AdvancedPIDController>(dt, kd_solver);
        pid_controller->setResetPose(reset_pose_);
    }
    pid_controller->setKpKiParams(friction_, ki_);
    pid_controller->setNonlinearParams(friction_alpha_, 0.001f);

    if (mode_ == ControlMode::MIT_MIX) {
        manager_->compute_dynamic_torque = [this](const JointArray& q, const JointArray& target_q){ return this->pid_controller->computeControlTorque(q, target_q, get_joint_velocities()); };
    }
    else if (mode_ == ControlMode::MIT_DRAG) {
        manager_->compute_dynamic_torque = [this](const JointArray& q, const JointArray& target_q){ return this->compute_drag_dynamics(q, target_q); };
    }
    manager_->setEnableSafetyCheck(config.controller.enable_safety_check);
}

OpenEAIArm::~OpenEAIArm() {
    if (manager_) manager_->stop();
    // if (motor_ctl_) disable_all();
    for (auto* m : motors_) delete m;
}

void OpenEAIArm::enable_all() {
    for (auto* m : motors_) {
        motor_ctl_->enable(*m);
    }
}

void OpenEAIArm::disable_all() {
    for (auto* m : motors_) motor_ctl_->disable(*m);
}

void OpenEAIArm::joint_step(const JointArray& joint_angles, 
                         const JointArray& joint_velocities, 
                         const JointArray& joint_torques)
{
    JointArray q = joint_angles;
    JointArray dq = joint_velocities;
    JointArray tau = joint_torques;
    JointArray clipped_q;
    for (size_t i=0; i<NUM_JOINTS; ++i)
        clipped_q[i] = std::min(std::max(q[i], joint_limits_low_[i]), joint_limits_high_[i]);
    manager_->move(clipped_q, dq, tau);
}

void OpenEAIArm::go_home(float move_time)
{
    manager_->move(reset_pose_, std::nullopt, std::nullopt, kp_, kd_, move_time);
    std::this_thread::sleep_for(std::chrono::duration<float>(move_time));
}

void OpenEAIArm::reset(float move_time, float angle_jump_threshold) {
    JointArray current_joints = get_joint_positions();
    int first_jump_joint_index = -1;
    for (size_t i = 0; i < NUM_JOINTS; ++i) {
        if (std::fabs(current_joints[i]) > angle_jump_threshold) {
            first_jump_joint_index = static_cast<int>(i);
            break;
        }
    }
    if (first_jump_joint_index != -1) {
        char cont = 'n';
        std::cout << "Error! Large Angle Jump Detected. Check if the robot is in a safe state and the configuration file is correct." << std::endl;
        std::cout << "Joint " << first_jump_joint_index + 1 << " has a jump of " << current_joints[first_jump_joint_index]
                  << " rad which exceeds the threshold of " << angle_jump_threshold << " rad." << std::endl;
        std::cout << "Continue? (y/n): ";
        std::cin >> cont;
        if (cont != 'y' && cont != 'Y') {
            disable_all();
            exit(-1);
        }
    }
    go_home(move_time);
}

OpenEAIArm::JointArray OpenEAIArm::get_joint_positions() const {
    return q_phys_to_control(manager_->getPosition());
}
OpenEAIArm::JointArray OpenEAIArm::get_joint_velocities() const {
    return manager_->getVelocity();
}
OpenEAIArm::JointArray OpenEAIArm::get_joint_torques() const {
    return manager_->getTau();
}
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

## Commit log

2026-02-02 Revise README for OpenEAI Arm project
    Updated README to include detailed project information, highlights, specifications, repository contents, build guide, and software quick start.
2026-02-05 upload control library for OpenEAI-Arm
    [STEP.csv, STEP.origin.urdf, STEP.sdf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]
2026-02-08 create files
    [JXS-01-01.DWG, JXS-01-02.DWG, JXS-01-03.DWG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]
2026-02-08 Fix image link for OpenEAI Arm in README
    Updated image source link in README.
2026-02-08 Change status to public release with full documentation
    Updated status from private preview to public release, including details on BOM, mechanical drawings, and assembly instructions.
2026-02-09 clean simple test codes
    [STEP.csv, STEP.origin.urdf, STEP.sdf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]
2026-02-09 add reference for DAMIAO motor driver
2026-02-09 fix: move urdf package to ros2
    [STEP.csv, STEP.sdf, STEP.urdf]
2026-02-10 fix: fix urdf path in codes
    [OpenEAIArm.cpp, default.yml, default_right.yml]
2026-02-10 fix: upload meshes for urdf
    [base_link.STL, link1.STL]
2026-02-10 feat: add online mode switch
2026-02-10 feat: add switch mode support for ROS2
2026-02-23 fix: fix starup failing in sim mode witout tty devices and update README installation guides
    [OpenEAIArm.cpp, collect_data.py]
2026-02-24 Add TODO note to assembly instructions README
2026-02-25 Remove Assembly Guide reference
    Remove assembly guide reference from README
2026-02-25 renew the BOM
    [BOM.xlsx]
2026-02-25 add GRIP STEP and STL
    [Clamping Jaw v3-left.STEP, Clamping Jaw v3-left.STL, Clamping Jaw v3.STEP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]
2026-03-24 feat: improve gravity computation for arm
    [STEP.urdf]
2026-09-19 docs: remove motor-project cross-reference
